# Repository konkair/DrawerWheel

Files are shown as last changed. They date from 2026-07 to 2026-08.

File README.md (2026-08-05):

<h1 align="center">Before You Begin</h1>
 
<p align="center">
  Models related to the steering wheel (paddle shift, wheel encoder) are designed for this steering wheel:
  <br><br>
 621088206-c9d27bfe-b4da-4281-bfc6-63039ef5ae99-Photoroom
  
</p>
<p align="center">
  (You can buy it secondhand; that's what I did.)
   </p>

# Full Build
zz



2e02f5b3-c47f-4aac-a90a-409e35e45135

*You can take detailed measurements yourself using the full-build model.*

# Why Im Building This?

I'm building this project because I want a steering wheel, but they're expensive and you can actually make better than the ones on the market for cheaper (I mean, I guess?). and at the same time this project will teach you (and me) a lot.
and you might be wondering why I didn't use a 3D printer or buy new materials to make a case;

this drawer is useless. Why wouldn't I use it? (and stronger than 3D printed cases)

# 3D Part Guide

### Desk clamp

In the 76th layer, there is a stop. In this layer, you need to insert the M12 hex nut into this place:


Then resume printing.

### Thumb Screw Knob

Just print it as normal, then glue the M12 hex-headed screw into this spot.



*There is nothing special about the other parts, but you need to use the 3MF file that I uploaded to GitHub because the settings for each part are different.*

# Build Guide

You can figure out how to build this project by reviewing the fullbuild model; I'm thinking of putting together a short guide after I build the project, but I'm not sure yet.

This is the schematic for this project
<div align="center">

 <p>(This schematic is not final and may change as the project progresses. And this is actually my first schematic.)</p>
</div>

The Arduino Leonardo will be sufficient for a project of this power, I'm not using the ESP32-3S or STM32 because the softwares made for these microcontrollers is usually for direct drive, but this project is not direct drive, so it does not require a lot processing power and there is a software for the Arduino Leonardo that is specifically designed for these modules and project purpose: https://github.com/ranenbg/Arduino-FFB-wheel This is the software and the original wiring diagram can be found at that link.

<div align="center">

# Markdown Billl of Materials

(These links lead to local sellers in Turkiye.)
| Part | QTY | Link |
| :--- | :---: | :--- |
| Rotary Encoder E6B2-CWZ6C 1000 Pulse | 1 | https://www.direnc.net/rotary-encoder-e6b2-cwz6c-1000-pulse |
| Arduino Leonardo R3 Klon | 1 | https://www.voltaj.net/arduino-leonardo-r3-klon-usb-kablo-pmu1486 |
| 12V 30A Power Supply | 1 | https://www.robolinkmarket.com/12v-30a-metal-kasa-adaptor |
| 14 AWG Silicone Cable (black) | 1 | https://www.robolinkmarket.com/14-awg-silikon-kablo-1-metre-siyah |
| 14 AWG Silicone Cable (red) | 1 | https://www.robolinkmarket.com/14-awg-silikon-kablo-1-metre-kirmizi |
| GT2 Closed-End Belt - 280mm (Buy 240mm if found) | 1 | https://www.robo90.com/gt2-6mm-kapali-zamanlama-kayisi-280mm-uzunluk |
| BTS7960B 40-Amp Motor Driver Board | 1 | https://www.voltaj.net/43a-5-27v-cift-bts7960b-h-kopru-yuksek-guc-motor-surucu-modulu-pmu1135 |
| 20-Tooth GT2-6mm Pulley - 5mm Shaft Diameter | 1 | https://www.robolinkmarket.com/20-dis-gt2-6mm-kasnak-5mm-saft-capi |
| GT2 6mm Toothless Pulley with Bearings - 5mm Shaft Diameter | 1 | https://www.robolinkmarket.com/gt2-6mm-dissiz-rulmanli-5mm-kasnak-siyah |
| KP000 Bearing (10 mm) - P000 | 2 | https://www.robolinkmarket.com/kp000-rulman-10mm |
| RS 775 DC Motor - 12V - 3000 RPM - Drill Motor | 1 | https://www.robo90.com/rs-775-dc-motor-12v-3000-rpm-matkap-motoru |
| 10mm Chrome-Plated Induction Shaft - 300mm | 1 | https://www.robo90.com/10mm-krom-kapli-induksiyonlu-mil-300mm |
| Insert Nut M5 | 20 | https://www.rhino3dprinter.com/urun/insert-somun-m5 |
| M6 Locknut | 4 | https://www.hirdavatim.com.tr/urun/fiberli-somun-celik-m5-m39-m5 |
| M5 Locknut | 6 | https://www.hirdavatim.com.tr/urun/fiberli-somun-celik-m5-m39-m5 |
| M3 Hex Nut | 14 | https://www.hirdavatim.com.tr/urun/metrik-normal-celik-somun-m3-m48-m5 |
| M12 Hex Nut | 2 | https://www.hirdavatim.com.tr/urun/metrik-normal-celik-somun-m3-m48-m5 |
| M5 Hex Nut | 2 | https://www.hirdavatim.com.tr/urun/metrik-normal-celik-somun-m3-m48-m5 |
| M6 40mm Allen Screw | 4 | https://www.hirdavatim.com.tr/urun/m6-imbus-civatalar-8-8-kalite-m6-40-mm |
| M3 20mm Pan Head Screw | 2 | N/A |
| M3 30mm Pan Head Screw | 4 | N/A |
| M3 50mm Pan Head Screw | 4 | N/A |
| M3 12mm Pan Head Screw | 4 | N/A |
| M5 30mm Allen Screw | 3 | https://www.hirdavatim.com.tr/urun/m6-imbus-civatalar-8-8-kalite-m6-40-mm |
| M12 50mm Hex Head Screw | 2 | https://www.hirdavatim.com.tr/urun/m12-anahtar-basli-celik-civatalar-8-8-kalite-m12x50-mm |
| M5 12mm Allen Screw | 1 | https://www.hirdavatim.com.tr/urun/m6-imbus-civatalar-8-8-kalite-m6-40-mm |
| M5 20mm Allen Screw | 1 | https://www.hirdavatim.com.tr/urun/m6-imbus-civatalar-8-8-kalite-m6-40-mm |
| 3.5X50mm Wood Screw (Pack of 20 - Min order) | 6 | https://www.hepsiburada.com/meridyen-3-5x18-mm-sunta-vidasi-50-adet-p-HBV00000JIT71 |
| 3.20mmX18.5 Wood Screw | 8 | N/A |
| M5 Washer | 14 | https://www.hirdavatim.com.tr/urun/metrik-demir-pul-cesitleri-05-mm |
| M6 Washer | 4 | https://www.hirdavatim.com.tr/urun/metrik-demir-pul-cesitleri-05-mm |
| Estimated Total Price (~$70 - $90) | | |

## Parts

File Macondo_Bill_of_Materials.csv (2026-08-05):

Part | QTY | TRY_Total | USD_Total | Link
Rotary Encoder E6B2-CWZ6C 1000 Pulse | 1 | 639.30 | 13.44 | https://www.direnc.net/rotary-encoder-e6b2-cwz6c-1000-pulse
Arduino Leonardo R3 Klon | 1 | 492.34 | 10.35 | https://www.robotistan.com/arduino-tabanli-leonardo-r3-gelistirme-karti
3.5X50mm Wood Screw (Pack of 20 - Min order) | 20 | 149.98 | 3.15 | https://www.hepsiburada.com/meridyen-sunta-vidasi-3-5x50-mm-p-HBV000007EZU9?magaza=Gelecek%20Market
BTS7960B 40-Amp Motor Driver | 1 | 227.31 | 4.78 | https://www.direnc.net/bts7960b-40-amper-motor-surucu-modulu-1
IC170 Long-Shaft Micro Switch | 2 | 47.61 | 1.00 | https://www.robotistan.com/ic170-uzun-palet-mikrosvic
Total Cost | 39.84 USD

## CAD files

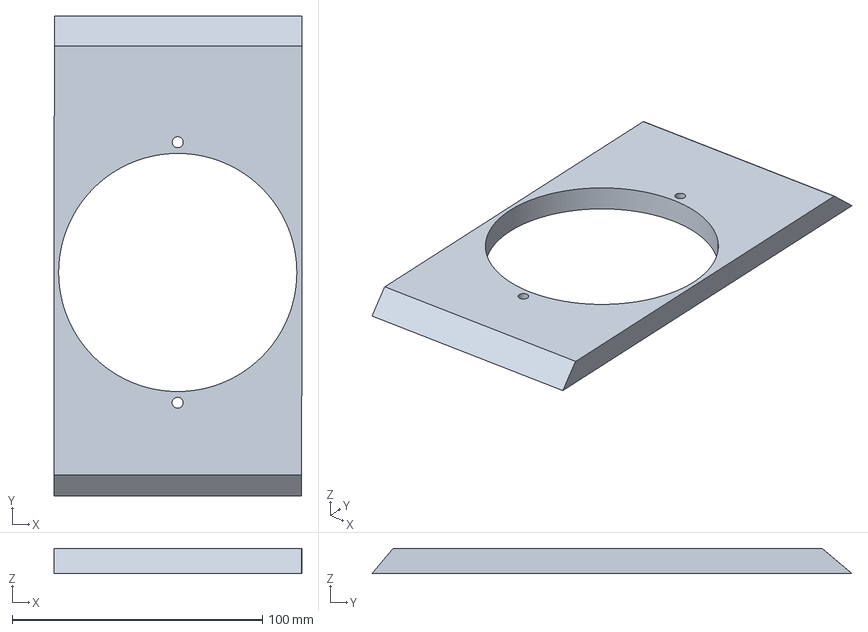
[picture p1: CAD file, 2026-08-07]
3MF Files/FanShroudPart1.3mf
99.1 x 191.9 x 10.0 mm

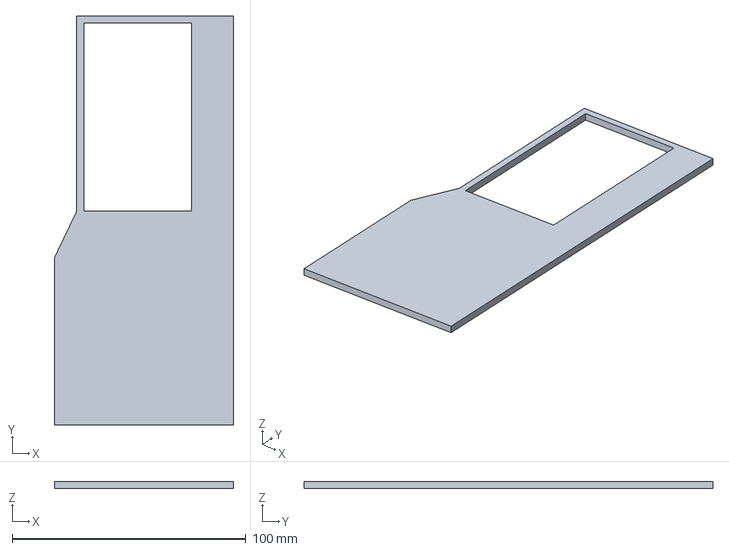
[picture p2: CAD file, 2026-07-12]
DrawerWheelModels/STEP Models/AirflowCover.step
76.8 x 175.1 x 3.10 mm

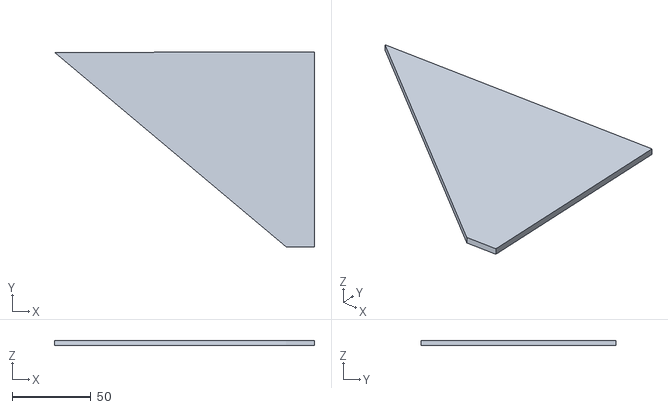
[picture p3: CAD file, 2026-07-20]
STL Files/FanShroudPart7.stl
164.9 x 123.5 x 3.10

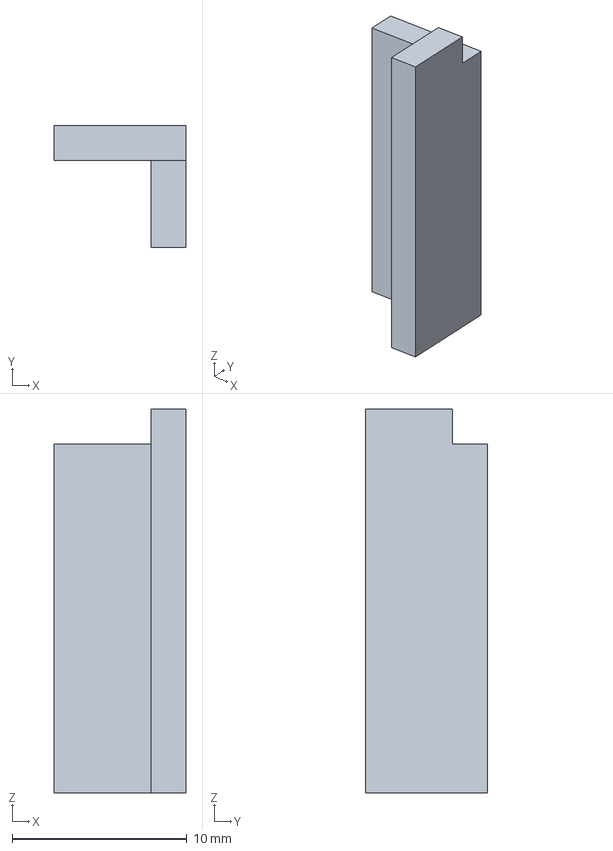
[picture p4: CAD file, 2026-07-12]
3MF Files/mdfbracketmini.3mf
7.54 x 7.00 x 22.0 mm

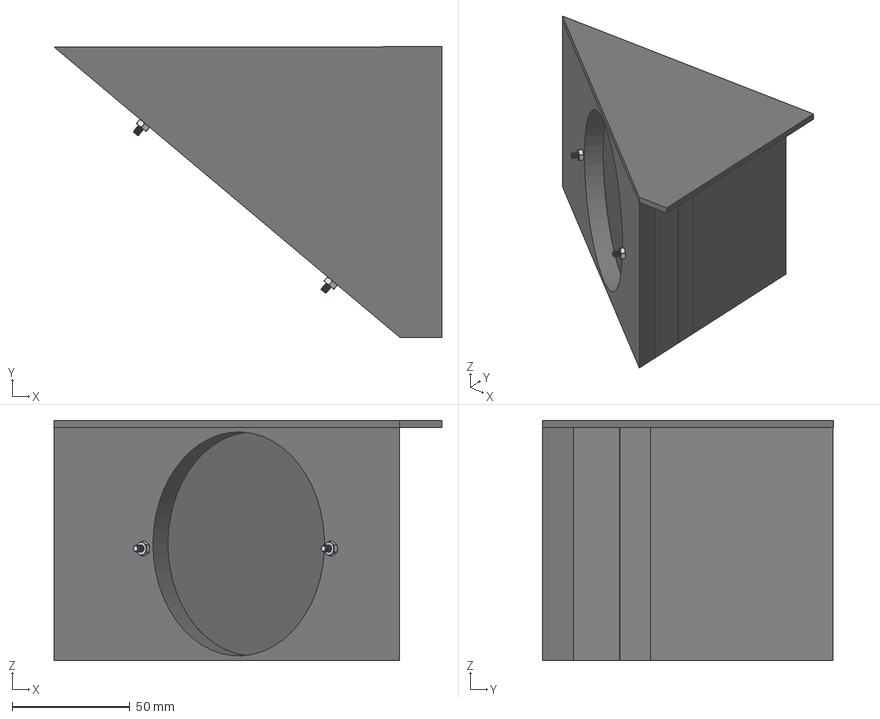
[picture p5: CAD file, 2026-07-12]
DrawerWheelModels/STEP Models/FanShroud(Xbox360Slim).step
164.9 x 123.5 x 102.1 mm

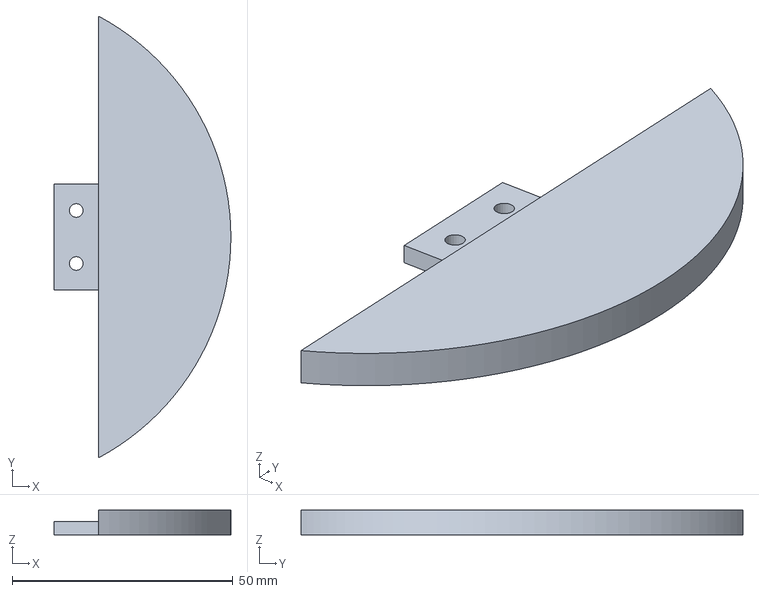
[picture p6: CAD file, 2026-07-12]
3MF Files/Paddle.3mf
40.0 x 100.0 x 5.60 mm

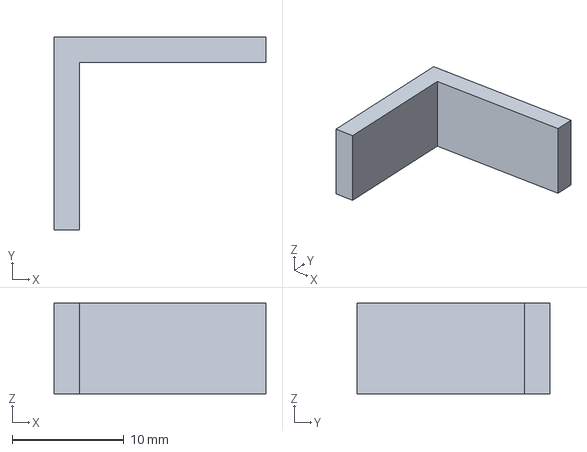
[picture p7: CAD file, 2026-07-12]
DrawerWheelModels/STEP Models/AirflowWallCornerBracket.step
19.0 x 17.3 x 8.15 mm

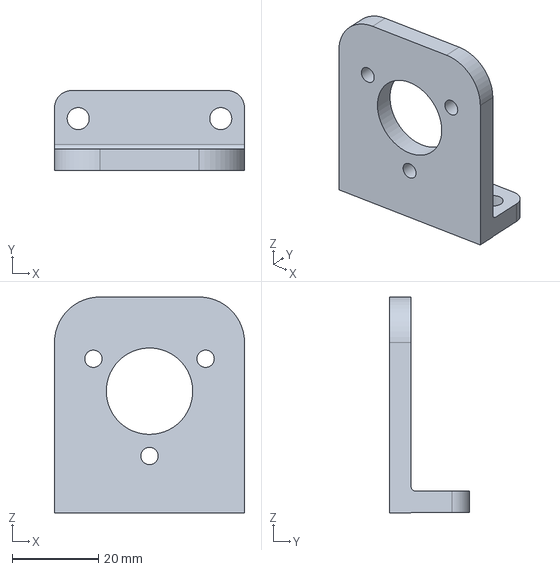
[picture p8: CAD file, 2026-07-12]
DrawerWheelModels/STEP Models/EncoderBracket (1).step
44.0 x 18.5 x 50.0 mm

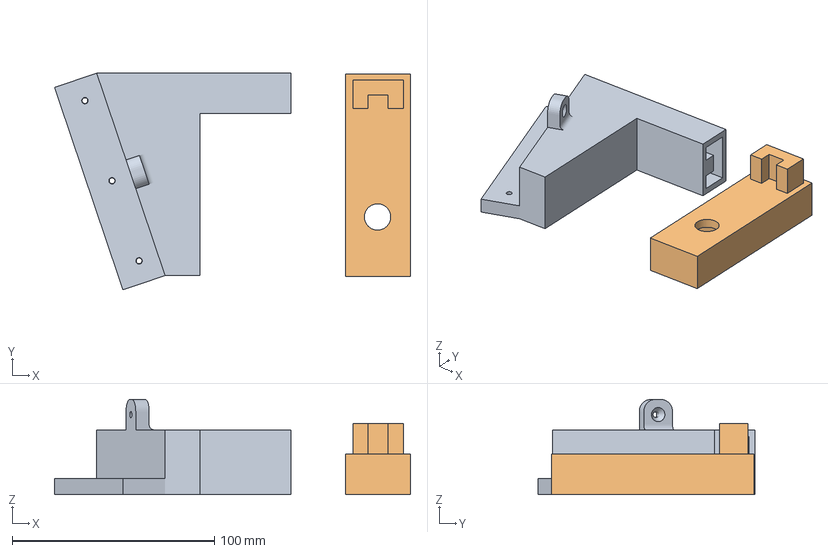
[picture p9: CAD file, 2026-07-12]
3MF Files/DeskClamp.3mf
175.9 x 107.0 x 47.0 mm
ustparca.stl
deliklisomunlualt.stl

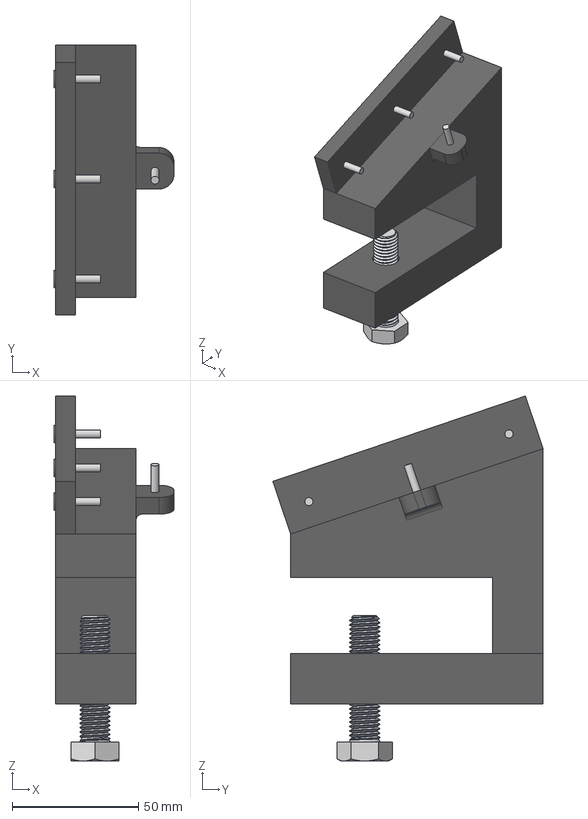
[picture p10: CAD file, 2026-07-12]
DrawerWheelModels/STEP Models/DeskClamp.step
47.5 x 107.0 x 144.5 mm

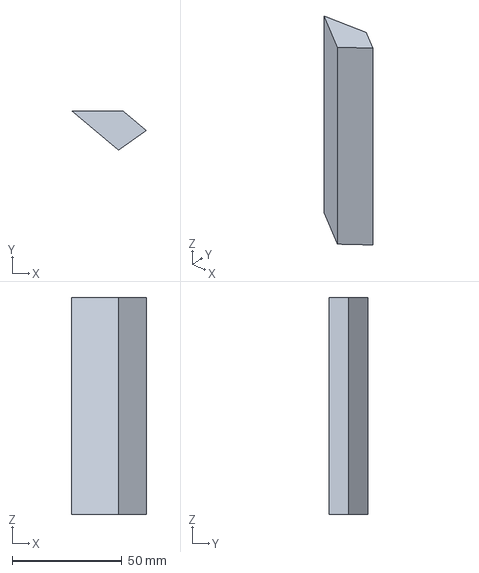
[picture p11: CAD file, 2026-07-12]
3MF Files/FanShroudPart5.3mf
34.0 x 17.9 x 99.0 mm

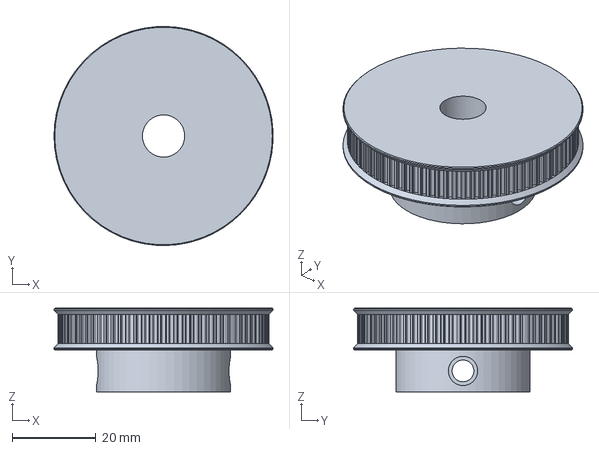
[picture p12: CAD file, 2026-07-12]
DrawerWheelModels/STEP Models/80tooth pulley.step
52.4 x 52.4 x 20.0 mm

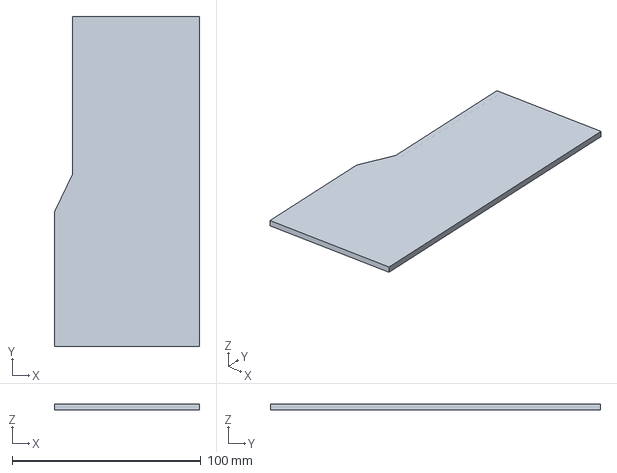
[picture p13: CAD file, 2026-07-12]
3MF Files/AirflowCover.3mf
76.8 x 175.1 x 3.16 mm

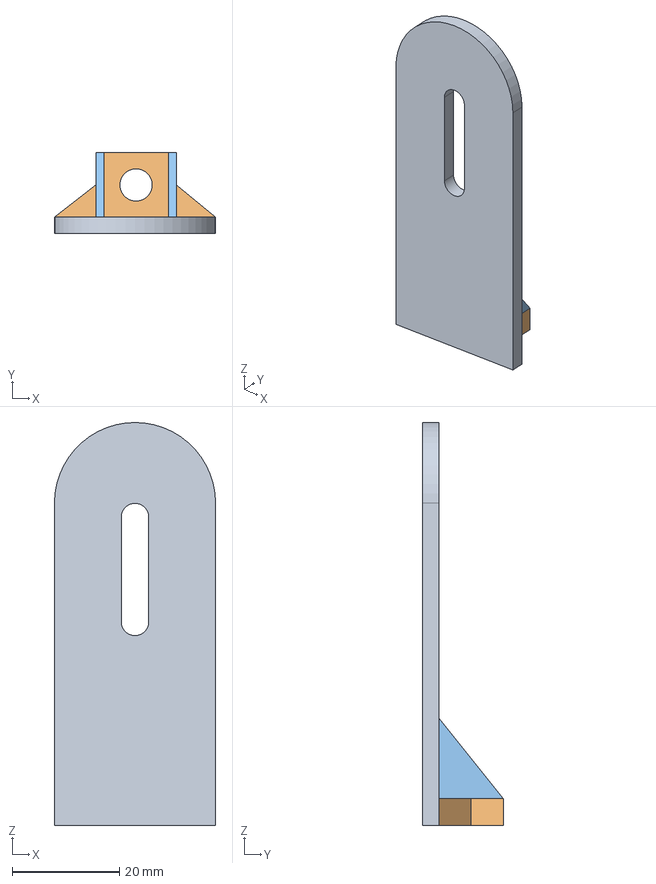
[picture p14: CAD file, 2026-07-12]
DrawerWheelModels/STEP Models/BeltTensioner.step
30.0 x 15.0 x 75.0 mm

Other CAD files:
3MF Files/FanShroudPart7cover.3mf
3MF Files/KP000 ElevationPart.3mf
DrawerWheelModels/STEP Models/MDF Bracket.step
3MF Files/Paddle Shift Wheel Part.3mf
3MF Files/80tooth pulley.3mf
3MF Files/AirflowWallCornerBracket.3mf
3MF Files/BeltTensioner.3mf
3MF Files/EncoderBracket (1).3mf
3MF Files/EncoderCoupler.3mf
3MF Files/FanShroudPart2.3mf
3MF Files/FanShroudPart3.3mf
3MF Files/FanShroudPart4.3mf
3MF Files/FanShroudPart6.3mf
3MF Files/Paddle Shift moving part.3mf
3MF Files/ThumbScrewKnob.3mf
3MF Files/WheelCoupler.3mf
3MF Files/mdfbracket.3mf
3MF Files/paddleshift_holder.3mf
DrawerWheelModels/F3D Models/80tooth pulley.f3d
DrawerWheelModels/F3D Models/AirflowCover.f3d
DrawerWheelModels/F3D Models/AirflowWallCornerBracket.f3d
DrawerWheelModels/F3D Models/BeltTensioner.f3d
DrawerWheelModels/F3D Models/DeskClamp.f3d
DrawerWheelModels/F3D Models/EncoderBracket.f3d
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

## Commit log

2026-05-29 Ceated README and added bom
2026-06-20 BOM update
2026-06-22 BOM update
    microcontroller changed
2026-06-24 3D Models Added
    [80-ToothPulley.f3d, 80tooth pulley.step, BeltTensioner.f3d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]
2026-06-26 Added Schematic
    This schematic is not final and may change as the project progresses.
    [Wheel.kicad_sch]
2026-06-26 BOM and Schematic
2026-07-08 BOM csv added
    [Bill of Materials.csv]
2026-07-11 Update Bill of Materials.csv
    [Bill of Materials.csv]
2026-07-12 Added 3MF Files
    [80tooth pulley.3mf, AirflowCover.3mf, AirflowWallCornerBracket.3mf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]
2026-07-12 DrawerWheelModels Updated
    [80tooth pulley.f3d, 80tooth pulley.step, AirflowCover.f3d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]
2026-07-20 Added STL Files
    [80tooth pulley.stl, AirflowCover.stl, AirflowWallCornerBracket.stl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]
2026-08-04 Added BOM for macondo
    [Macondo_Bill_of_Materials.csv]
2026-08-07 Screw hole relocation
    The issue with the Xbox 360 fan not aligning with the screw holes has been resolved
    [FanShroudPart1.3mf]
